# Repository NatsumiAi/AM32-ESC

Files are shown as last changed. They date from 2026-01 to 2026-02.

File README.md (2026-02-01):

<!--
 * @Author: BaiLiang
 * @Date: 2026-01-17 11:20:38
 * @LastEditTime: 2026-02-01 10:15:56
 * @Description: 
-->

# AM32 开源电调 (STM32G071 版)





本项目是一款基于 **AM32** 开源固件的高性能无刷电调（ESC）。专为“全国大学生智能汽车竞赛”及高频动力系统设计，采用高集成度方案，支持大电流输出与精准的电流控制。

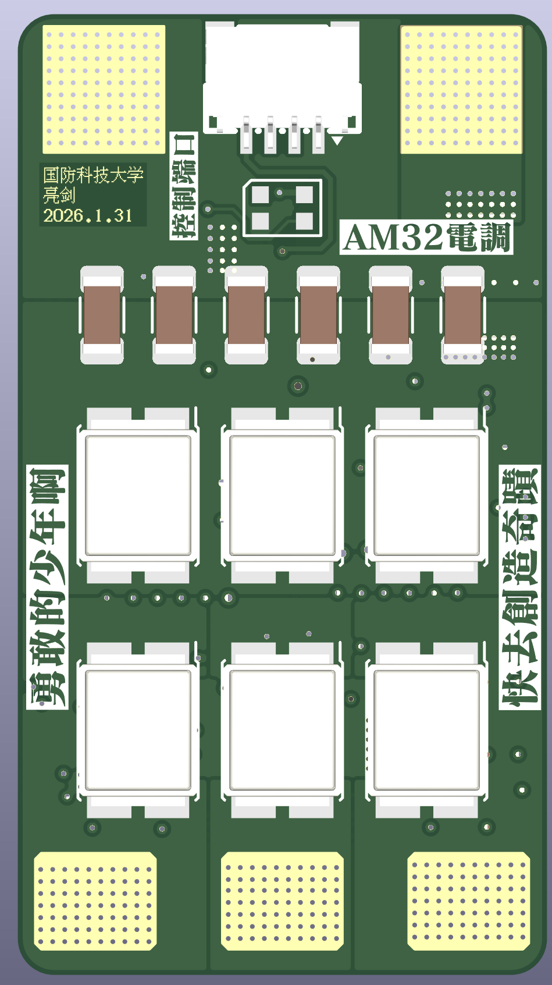
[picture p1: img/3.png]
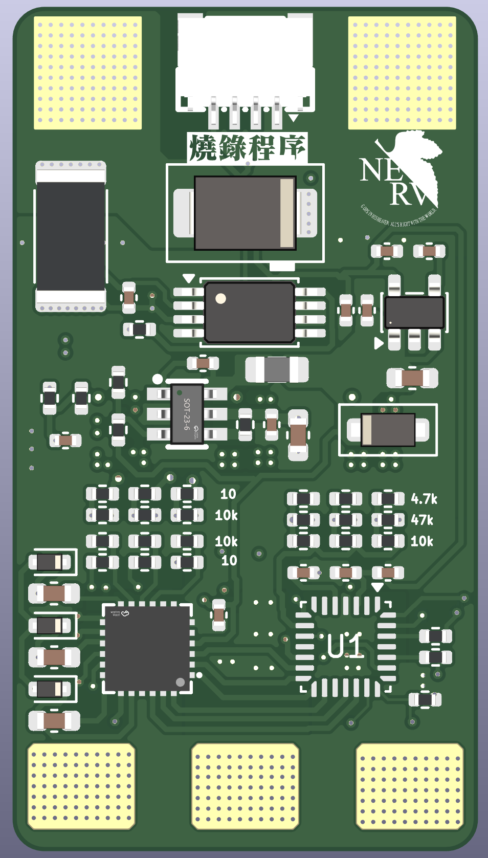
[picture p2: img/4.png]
 

## 🚀 项目特性

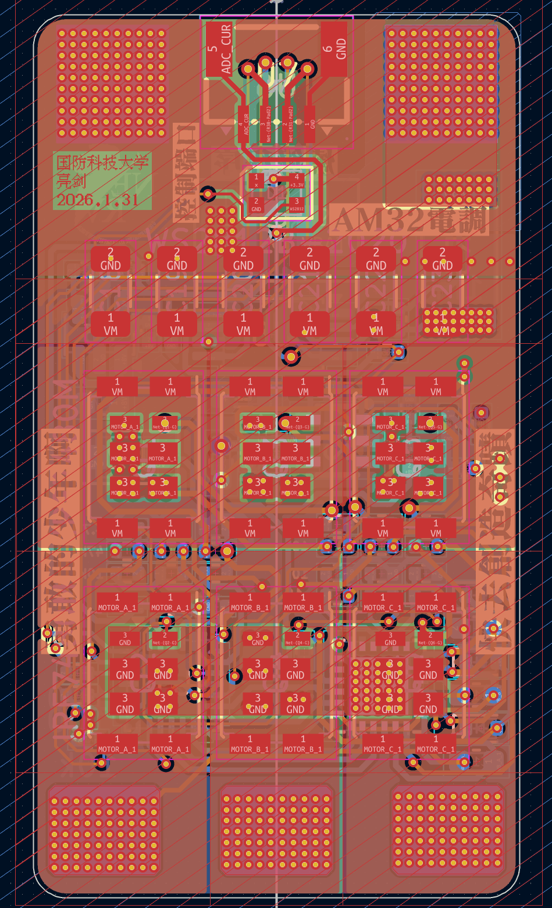
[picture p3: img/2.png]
PCB Layout


- **核心处理器**: STM32G071GBU6N，ARM Cortex-M0+ 内核，高性能且具有极佳的性价比。
- **驱动芯片**: FD6288Q 三相半桥驱动，成熟稳定。
- **功率 MOSFET**: IRF7480M DirectFET 封装，极低导通内阻（RDSon），散热效率极高。
- **电流检测**: 搭载 **INA240A1** 高侧/线电流检测放大器，提供极高精度的电流反馈，支持精准的电流限幅和力矩控制。
- **电源管理**:
    - **JW5026** Buck 电路将电池电压转换为 8V（驱动电压）。
    - **AP2210K** LDO 提供 3.3V 给 MCU 和逻辑电路。
- **状态指示**: 集成 **WS2812B** RGB 灯珠，可根据电调状态切换颜色。
- **接口**:
    - 标准 SWD 调试接口。
    - 支持 PWM/DShot 信号输入。
    - 支持 UART 异步通信（用于电调配置或遥测）。

## 🛠 硬件规格

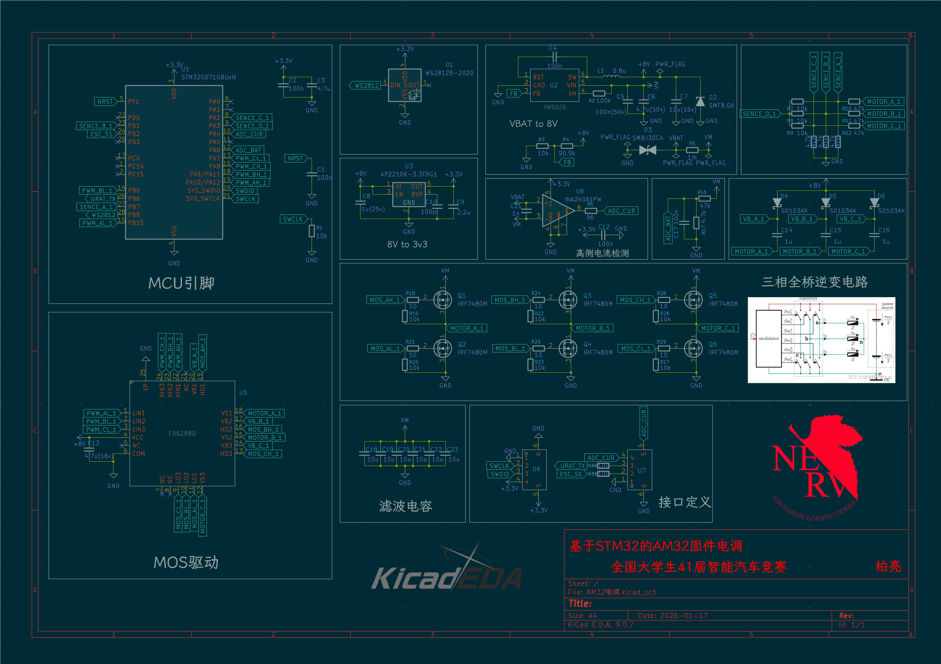
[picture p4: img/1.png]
Schematic


| 参数 | 规格 |
| :--- | :--- |
| **输入电压** | 2S - 4S LiPo (根据电容与 Buck 电路限制) |
| **持续电流** | 建议 40A+ (取决于 PCB 散热) |
| **固件** | AM32 (Multi-Protocol BLDC) |
| **PCB 层数** | 2/4 层 (建议使用 2oz 铜厚) |
| **设计软件** | KiCad 9.0.7 |

## 📂 硬件连接定义 (引脚映射)

根据原理图设计，关键引脚定义如下（编译 AM32 固件时需参考）：

- **PWM 输入 (Signal)**: `PA2` (ESC_S1)
- **电感/相电压感测**: `PA3 (SENCE_O_1)`, `PD1 (SENCE_B_1)`, `PB7 (SENCE_A_1)`
- **电流检测 (Current)**: `PA4 (ADC_CUR)`
- **电压检测 (V-Bat)**: `PA1 (ADC_BAT)`
- **驱动控制 (Gate Drivers)**:
    - Phase A: `PA10 (H)`, `PB15 (L)`
    - Phase B: `PA9 (H)`, `PB14 (L)`
    - Phase C: `PA8 (H)`, `PB13 (L)`
- **RGB LED**: `PB8 (WS2812)`

## 💾 固件烧录与配置

本项目运行 **AM32** 开源固件。

1.  **固件源码/下载**:
    - AM32 官方 GitHub: [https://github.com/am32-esc/AM32](https://github.com/am32-esc/AM32)
    - 预编译固件下载: [AM32 Releases](https://github.com/am32-esc/AM32/releases)
2.  **配置工具**:
    - 建议使用官方在线配置器: [https://configurator.am32.ca/](https://configurator.am32.ca/)
3.  **烧录方式**:
    - 初次烧录：通过 ST-Link 连接板载 SWD 接口，使用 `STM32CubeProgrammer` 烧录 Bootloader。
    - 后续升级：可通过信号线进行串口升级。

## ⚠️ 免责声明

- 本项目为开源硬件，DIY 存在风险。在焊接和通电测试前，请务必检查电路是否存在短路。
- 建议初次通电时使用限流电源，以防止 MOSFET 烧毁。
- 作者不对使用本设计造成的任何直接或间接损失负责。

## 📜 许可协议

本项目硬件方案基于 [CERN Open Hardware Licence](https://ohwr.org/project/cernohl/wikis/Documents/CERN-OHL-version-2) 或 MIT 协议开源。固件部分遵循 AM32 原作者的 GPL v3 协议。

---
**设计者**: 柏亮 (Bailiang)
**所属单位**: 全国大学生41届智能汽车竞赛国防科技大学

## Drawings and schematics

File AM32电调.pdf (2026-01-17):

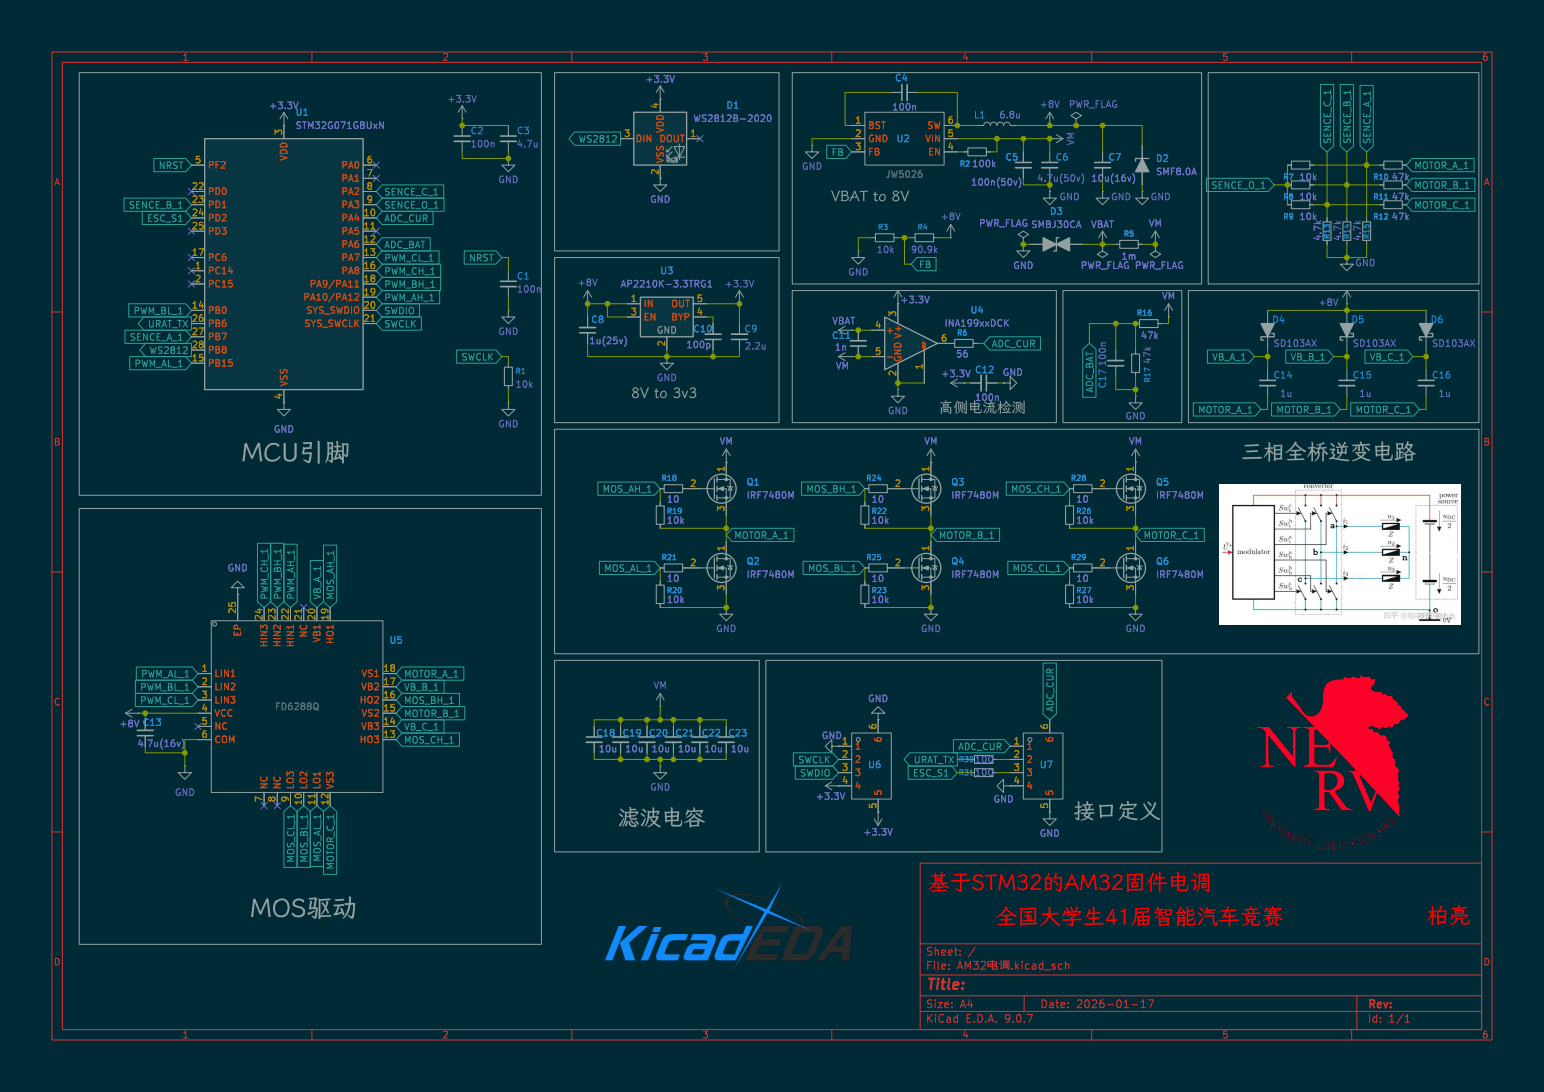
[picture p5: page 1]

þÿQhVýY'[fu41\Jfz€ýl}•fzÞ•[

Id: 1/1 Title: File: þÿAM32u5Œ.kicad_sch Sheet: /

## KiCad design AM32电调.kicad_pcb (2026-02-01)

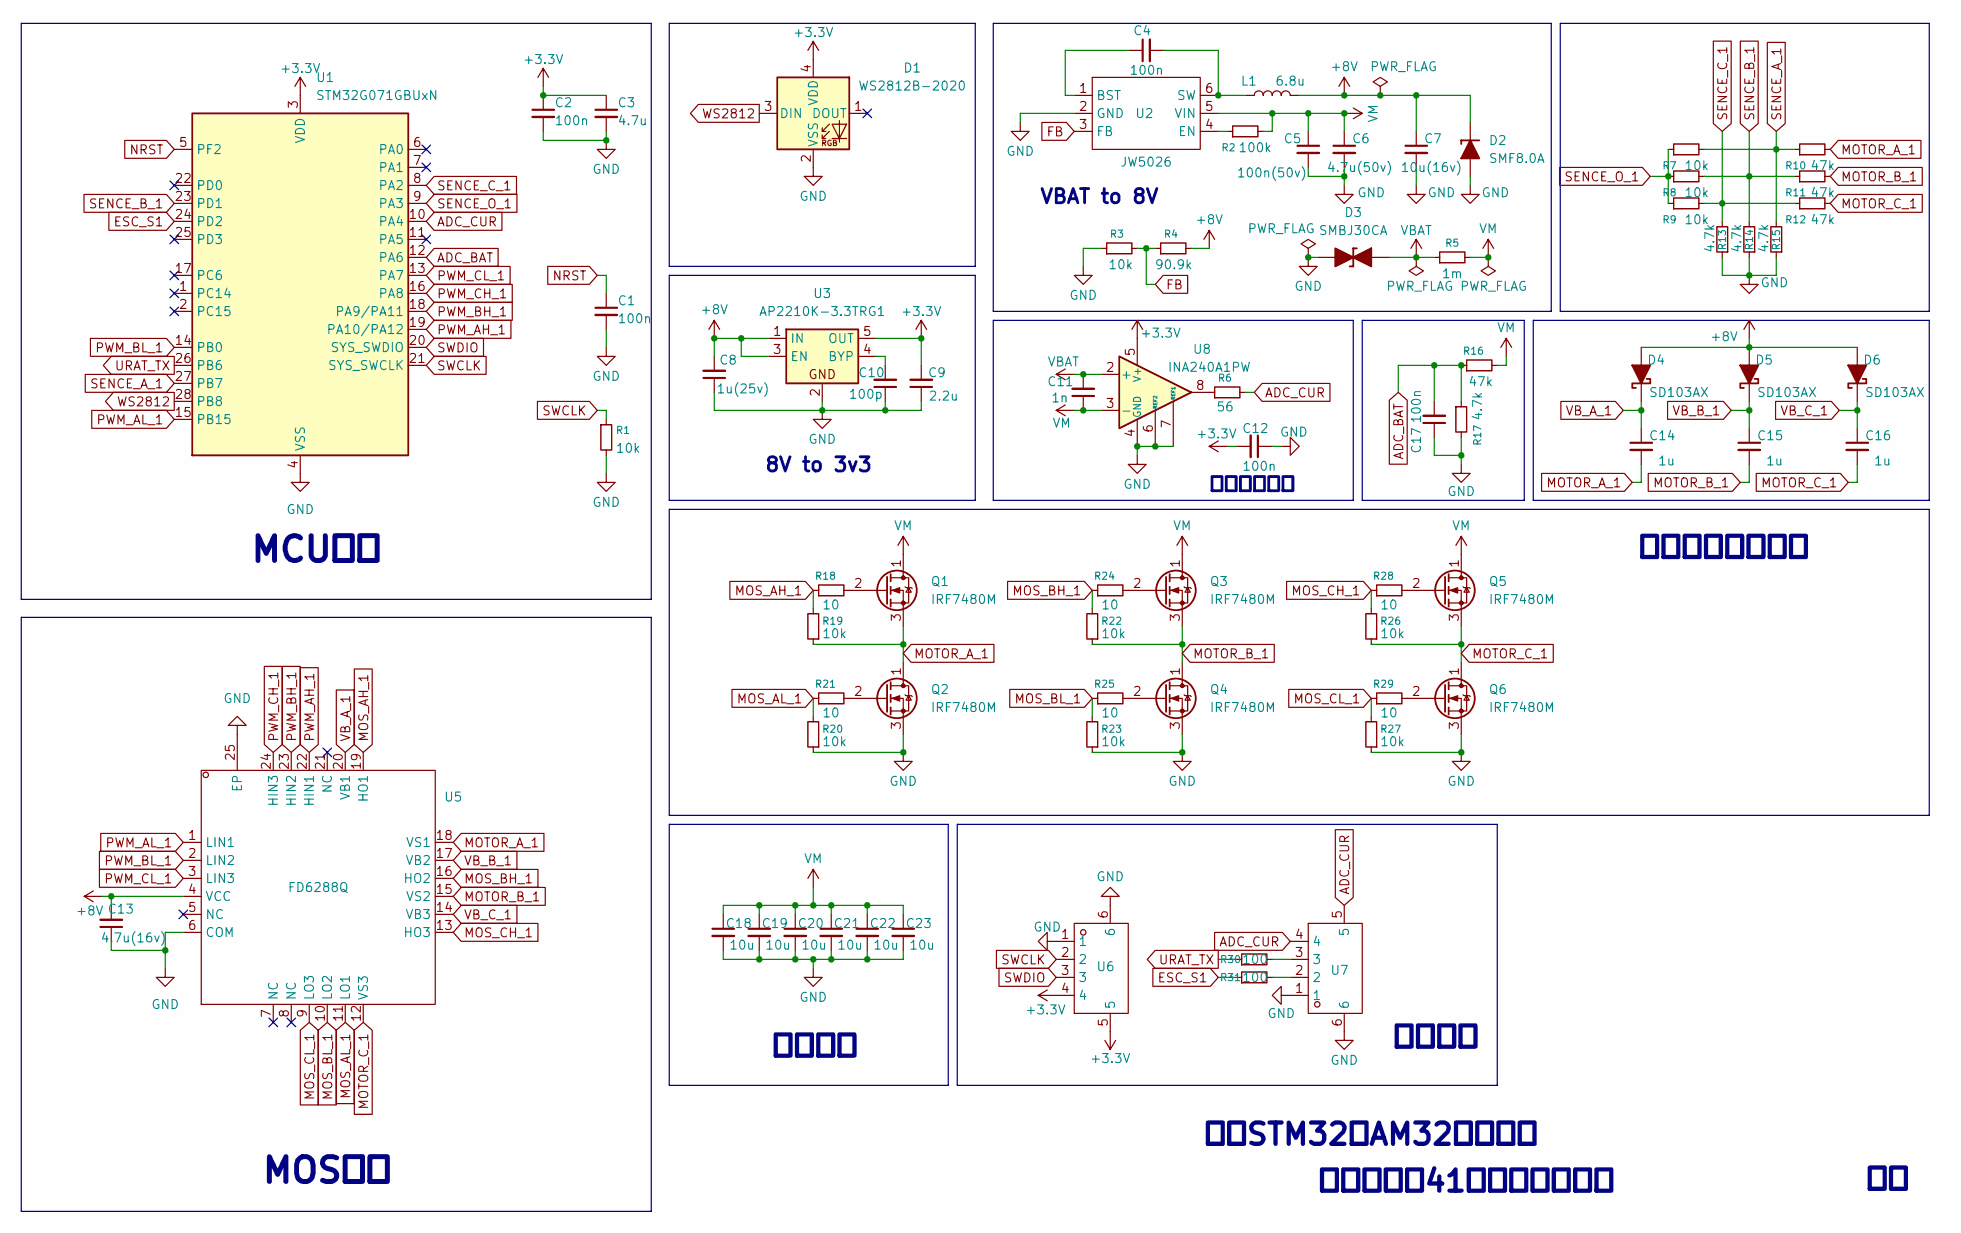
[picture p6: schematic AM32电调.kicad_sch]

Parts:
C1, C2, C4, C12, C17: 100n; C_0402_1005Metric
C3: 4.7u; C_0402_1005Metric
C5: 100n(50v); C_0402_1005Metric
C6: 4.7u(50v); C_0603_1608Metric
C7: 10u(16v); C_0603_1608Metric
C8: 1u(25v); C_0402_1005Metric
C9: 2.2u; C_0402_1005Metric
C10: 100p; C_0402_1005Metric
C11: 1n; C_0402_1005Metric
C13: 4.7u(16v); C_0402_1005Metric
C14, C15, C16: 1u; C_0603_1608Metric
C18, C19, C20, C21, C22, C23: 10u; C_1206_3216Metric
D1: WS2812B-2020; LED_WS2812B-2020_PLCC4_2.0x2.0mm
D2: SMF8.0A; D_SOD-123F_TVS
D3: SMBJ30CA; D_SMB
D4, D5, D6: SD103AX; D_SOD-523
L1: 6.8u; L_0805_2012Metric
Q1, Q2, Q3, Q4, Q5, Q6: IRF7480M; DirectFET_ME
R1, R3, R7, R8, R9, R19, R20, R22, R23, R26, R27: 10k; R_0402_1005Metric
R2: 100k; R_0402_1005Metric
R4: 90.9k; R_0402_1005Metric
R5: 1m; R_2512_6332Metric
R6: 56; R_0402_1005Metric
R10, R11, R12, R16: 47k; R_0402_1005Metric
R13, R14, R15, R17: 4.7k; R_0402_1005Metric
R18, R21, R24, R25, R28, R29: 10; R_0402_1005Metric
R30, R31: 100; R_0402_1005Metric
U1: STM32G071GBUxN; QFN-28_4x4mm_P0.5mm
U2: SOT-23-6_L2.9-W1.6-P0.95-LS2.8-BR; Manufacturer Part JW5026; LCSC Part Name 40V/1A 1.1MHz 同步降压转换器
U3: AP2210K-3.3TRG1; SOT-23-5
U5: QFN-24_L4.0-W4.0-P0.50-BL-EP2.6; Manufacturer Part FD6288Q; LCSC Part Name 三相250V栅极驱动器
U6, U7: CONN-SMD_4P-P1.00_MEGASTAR_ZX-SH1.0-4PWT; Manufacturer Part ZX-SH1.0-4PWT; LCSC Part Name 1x4P 间距:1mm 卧贴 系列:SH
U8: INA240A1PW; TSSOP-8_4.4x3mm_P0.65mm

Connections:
+3.3V: C2.1, C3.1, C9.2, C12.2, D1.4 (VDD), U1.3 (VDD), U3.5 (OUT), U6.4, U6.5, U8.5 (V+)
+8V: C7.1, C8.2, C13.2, D2.1 (K), D4.2 (A), D5.2 (A), D6.2 (A), L1.2, R4.2, U3.1 (IN), U3.3 (EN), U5.4 (VCC)
ADC_BAT: C17.2, R16.1, R17.1, U1.12 (PA6)
ADC_CUR: R6.2, U1.10 (PA4), U7.4, U7.5
ESC_S1: R31.1, U1.24 (PD2)
FB: R3.2, R4.1, U2.3 (FB)
GND: C1.2, C2.2, C3.2, C5.2, C6.2, C7.2, C8.1, C9.1, C10.1, C12.1, C13.1, C17.1, C18.2, C19.2, C20.2, C21.2, C22.2, C23.2, D1.2 (VSS), D2.2 (A), D3.1 (K), Q2.3 (S), Q4.3 (S), Q6.3 (S), R1.2, R3.1, R13.1, R14.1, R15.1, R17.2, R20.1, R23.1, R27.1, U1.4 (VSS), U2.2 (GND), U3.2, U5.6 (COM), U5.25 (EP), U6.1, U6.6, U7.1, U7.6, U8.1 (GND), U8.4 (GND), U8.6 (REF2), U8.7 (REF1)
MOS_AH_1: R18.1, R19.2, U5.19 (HO1)
MOS_AL_1: R20.2, R21.1, U5.11 (LO1)
MOS_BH_1: R22.2, R24.1, U5.16 (HO2)
MOS_BL_1: R23.2, R25.1, U5.10 (LO2)
MOS_CH_1: R26.2, R28.1, U5.13 (HO3)
MOS_CL_1: R27.2, R29.1, U5.9 (LO3)
MOTOR_A_1: C14.2, Q1.3 (S), Q2.1 (D), R10.2, R19.1, U5.18 (VS1)
MOTOR_B_1: C15.2, Q3.3 (S), Q4.1 (D), R11.2, R22.1, U5.15 (VS2)
MOTOR_C_1: C16.2, Q5.3 (S), Q6.1 (D), R12.2, R26.1, U5.12 (VS3)
NRST: C1.1, U1.5 (PF2)
unnamed: Q1.2 (G), R18.2
unnamed: Q2.2 (G), R21.2
unnamed: Q3.2 (G), R24.2
unnamed: Q4.2 (G), R25.2
unnamed: Q5.2 (G), R28.2
unnamed: Q6.2 (G), R29.2
unnamed: R6.1, U8.8
unnamed: R30.2, U7.3
unnamed: R31.2, U7.2
unnamed: C4.1, U2.1 (BST)
unnamed: R2.1, U2.4 (EN)
unnamed: C4.2, L1.1, U2.6 (SW)
unnamed: C10.2, U3.4 (BYP)
PWM_AH_1: U1.19 (PA10/PA12), U5.22 (HIN1)
PWM_AL_1: U1.15 (PB15), U5.1 (LIN1)
PWM_BH_1: U1.18 (PA9/PA11), U5.23 (HIN2)
PWM_BL_1: U1.14 (PB0), U5.2 (LIN2)
PWM_CH_1: U1.16 (PA8), U5.24 (HIN3)
PWM_CL_1: U1.13 (PA7), U5.3 (LIN3)
SENCE_A_1: R7.2, R10.1, R15.2, U1.27 (PB7)
SENCE_B_1: R8.2, R11.1, R14.2, U1.23 (PD1)
SENCE_C_1: R9.2, R12.1, R13.2, U1.8 (PA2)
SENCE_O_1: R7.1, R8.1, R9.1, U1.9 (PA3)
SWCLK: R1.1, U1.21 (SYS_SWCLK), U6.2
SWDIO: U1.20 (SYS_SWDIO), U6.3
URAT_TX: R30.1, U1.26 (PB6)
VBAT: C11.2, D3.2 (A), R5.1, U8.2 (+)
VB_A_1: C14.1, D4.1 (K), U5.20 (VB1)
VB_B_1: C15.1, D5.1 (K), U5.17 (VB2)
VB_C_1: C16.1, D6.1 (K), U5.14 (VB3)
VM: C5.1, C6.1, C11.1, C18.1, C19.1, C20.1, C21.1, C22.1, C23.1, Q1.1 (D), Q3.1 (D), Q5.1 (D), R2.2, R5.2, R16.2, U2.5 (VIN), U8.3 (-)
WS2812: D1.3 (DIN), U1.28 (PB8)

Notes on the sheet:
8V to 3v3
MOS驱动
滤波电容
MCU引脚
VBAT to 8V
接口定义
三相全桥逆变电路
高侧电流检测
基于STM32的AM32固件电调
全国大学生41届智能汽车竞赛

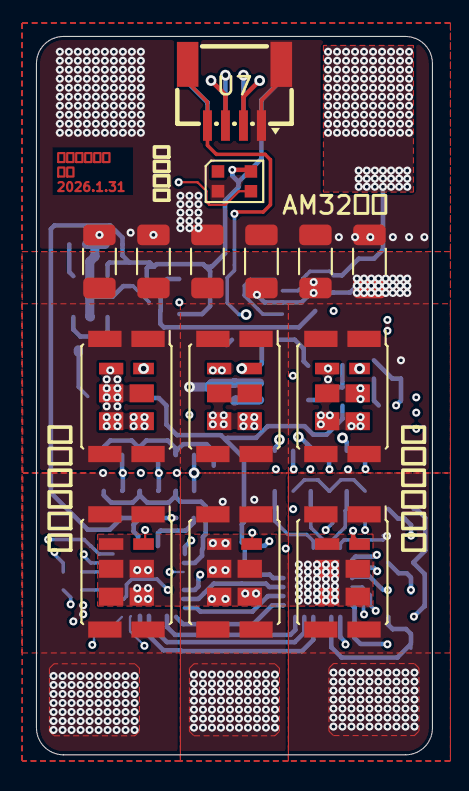
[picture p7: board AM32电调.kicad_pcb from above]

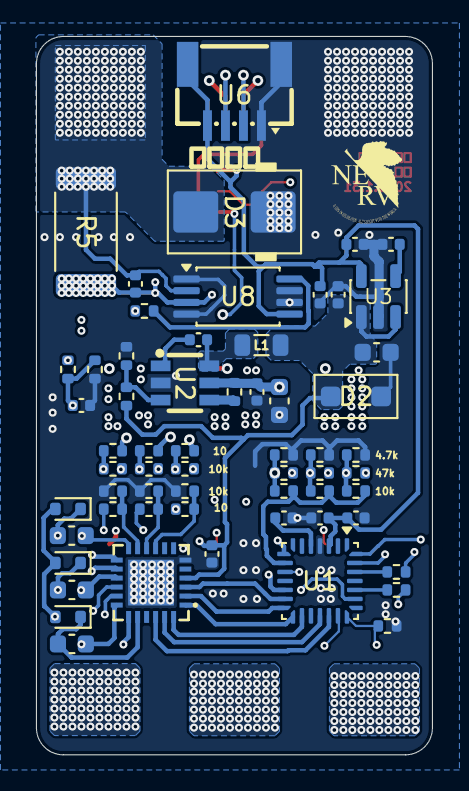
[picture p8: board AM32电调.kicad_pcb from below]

Board: 4 copper layers, 22.0 x 39.9 mm, 74 parts (60 on the bottom side), 49 nets.

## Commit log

2026-01-17 init: 原理图
2026-01-17 add: README
    [CONN-SMD_4P-P1.00_MEGASTAR_ZX-SH1.0-4PWT.step, QFN-24_L4.0-W4.0-H0.9-P0.50.step, SOT-23-6_L2.9-W1.6-H1.5-LS2.8-P0.95.step]
2026-02-01 ADD: final draft
    [AM32电调.kicad_pcb, AM32电调.kicad_sch]

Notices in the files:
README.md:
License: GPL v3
